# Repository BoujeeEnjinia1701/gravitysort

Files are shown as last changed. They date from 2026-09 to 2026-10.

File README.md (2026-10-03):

# GravitySort

     

**Area:** Mining · **TRL:** 3 of 9 (proof of concept on paper) · **Value-engineering target:** USD 455 (estimated cost USD 580) · **Difficulty:** 4 of 5

A mercury-free gravity concentrator for small-scale gold miners: a pedal- or motor-driven centrifugal bowl and shaking table combination that recovers fine gold without amalgamation.

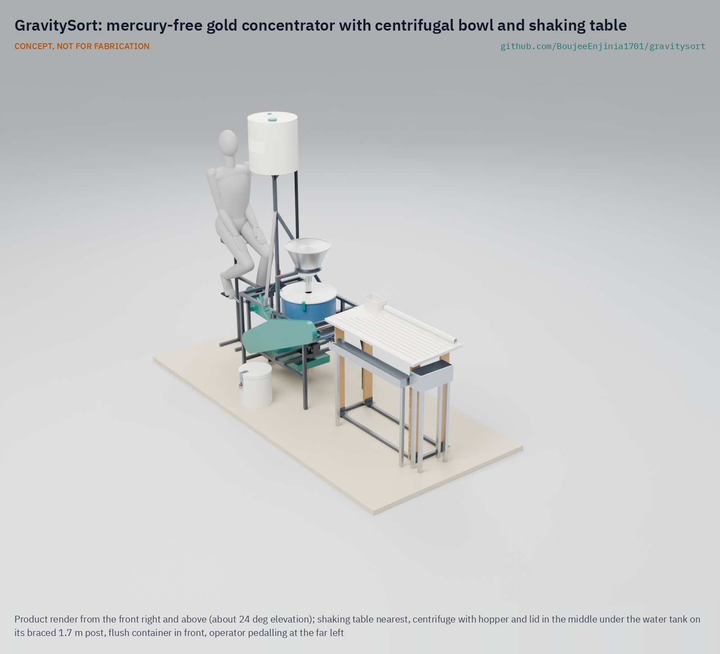
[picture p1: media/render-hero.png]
GravitySort: mercury-free gold concentrator with centrifugal bowl and shaking table, product render


[Exploded render](media/render-exploded.png) · [Detail render](media/render-detail.png) · [Interactive 3D model](media/viewer.html) · [Concept blueprint (PDF)](media/concept-blueprint.pdf) · [General arrangement GVS-DWG-001 (PDF)](cad/drawings/GVS-DWG-001.pdf) · [Sizing note GVS-CAL-001](docs/04-calcs/01-sizing.md) · [Prototype build plan](docs/05-build-plan.md) · [Design decisions register](docs/06-design-decisions.md) · [Review note](docs/REVIEW.md)

## Concept rationale

Miners use mercury because it catches fine gold cheaply, not because they want to. If a local workshop can build a machine that catches as much gold as mercury, or more, at a price a small group can pay back in weeks, miners gain an economic reason to stop, not only a legal one. GravitySort pairs the two gravity methods that each solve half the problem: a fluidized centrifugal bowl holds fine gold from a steady stream of milled ore, and a small shaking table cleans the bowl's concentrate down to a few tens of grams that can be smelted directly with borax. One pedal or motor drive runs both.

It is open and garage-buildable because commercial centrifuges and tables are imported, costly and hard to repair at a mine site. The frame is welded tube, the drive is bicycle parts and V-belts, the tub and tank are HDPE drums, and the bowl liner is cast in a printed mold, so a welder in a mining town can build, repair and adapt it, and anyone can check how it works.

## Burning platform

Artisanal and small-scale gold mining is the largest human source of mercury emissions to air: about 838 t in 2015, 37.7 % of the global total ([US EPA summary of the UNEP Global Mercury Assessment 2018](https://www.epa.gov/international-cooperation/mercury-emissions-global-context)). UNEP estimates that 10 to 15 million people work in the sector, including 4 to 5 million women and children, and that it produces about 12 to 15 % of the world's gold ([UNEP Global Mercury Partnership](https://www.unep.org/globalmercurypartnership/what-we-do/artisanal-and-small-scale-gold-mining-asgm)).

The pressure is rising. Gold averaged a record US$3,431/oz in 2025, up 44 % on the year ([World Gold Council](https://www.gold.org/goldhub/research/gold-demand-trends/gold-demand-trends-full-year-2025)), which raises the incentive to mine and the value of every gram lost. Yet whole-ore amalgamation in Colombian processing centers typically recovers only about 30 % of the gold ([Veiga et al., 2018](https://doi.org/10.1016/j.jclepro.2018.09.039)), so better gravity equipment can pay for itself as well as remove mercury.

## Where it could be used

### By industry

| Industry | Use |
| --- | --- |
| Artisanal and small-scale gold mining | Mercury-free primary concentration and clean-up for groups processing about 1 to 2 t of ore per day |
| Ore processing centers (entables) | Replace whole-ore amalgamation with a concentrate step, as national action plans require |
| Responsible gold supply chains | Refiners, traders and jewelers sourcing traceable mercury-free gold from certified small mines |
| Development and extension programmes | Demonstration unit for NGOs, cooperatives and government extension officers |
| Mining education | Teaching gravity separation in technical colleges and mining schools |
| Mineral exploration | Concentrating heavy minerals from stream sediment and trench samples in the field |

### By country or region

| Country or region | Why it matters there |
| --- | --- |
| Ghana | Illegal small-scale mining (galamsey) has silted rivers; Ghana Water reported raw water turbidity of about 14,000 NTU at one plant designed for 2,000 NTU ([GBC Ghana](https://www.gbcghanaonline.com/general-news/gwcl-attributes-water-supply-challenges-to-galamsey-activities/2024/)) |
| Peru | Gold mining cleared 95,751 ha of forest in the southeastern Peruvian Amazon from 1985 to 2017 ([Caballero Espejo et al., *Remote Sensing*, 2018](https://www.mdpi.com/2072-4292/10/12/1903)); Madre de Dios miners rely on mercury |
| Colombia | Mercury use in mining has been banned since July 2018 under Law 1658 of 2013 ([Mongabay](https://news.mongabay.com/2018/08/colombia-bans-the-use-of-mercury-in-mining/)), so miners need working alternatives |
| Philippines | In Benguet, the regional miners' federation reports all 15,000 members smelt gravity concentrates with borax instead of mercury ([Pure Earth](https://www.pureearth.org/filipino-gold-miners-borax-revolution/)), a model GravitySort's clean concentrate is designed to feed |
| European Union | Mercury exports and amalgamation in small-scale gold mining are prohibited ([Regulation (EU) 2017/852](https://eur-lex.europa.eu/eli/reg/2017/852/oj/eng)); EU buyers and programmes need mercury-free equipment to support abroad |

## What sparked the idea

The starting point was a single phrase in the Minamata Convention on Mercury, the treaty signed in Minamata, Japan, in October 2013. Its annex on artisanal and small-scale gold mining asks countries to eliminate the worst practices in the sector, including whole-ore amalgamation, in which mercury is mixed with all of the milled ore rather than with a small concentrate ([NRDC summary of the convention](https://www.nrdc.org/bio/susan-egan-keane/minamata-convention-what-it-means-artisanal-and-small-scale-gold-mining)). Ending that practice without ending the miners' income means putting a concentration step in front of the gold: something that turns tonnes of ore into a handful of heavy concentrate. GravitySort is that step, sized so the concentrate is small enough to smelt directly with borax and no mercury is needed at all.

## Problem

Artisanal and small-scale gold mining uses mercury to capture fine gold because it is cheap and works, poisoning miners, families and rivers. Mercury-free equipment exists but is costly and often recovers less fine gold. Design with, not for: requirements must come from co-design sessions and field trials with the intended users through a local partner.

Problem statement: [docs/01-problem.md](docs/01-problem.md)

## Concept

A welded steel frame carries a fluidized centrifugal bowl (220 mm lip, about 60 G at 730 rpm) that takes about 200 kg/h of ore milled below 2 mm, with a hopper screen above it and a water header tank on a braced 1.7 m post beside it, which gives the bowl's fluidization water its pressure without a pump. A pedal crank, or a 250 W motor through the lab's MotionCore module, turns the bowl through a jackshaft, bevel gearbox and V-belt; a bicycle disc brake stops it, and the lid opens only with the brake set. At the end of the day the same drive runs a 1,000 x 450 mm shaking table that cleans about 5.3 kg of bowl concentrate down to about 100 g for direct smelting with borax. The TRL 3 sizing note gives 48 W at the pedals, 1.19 m3/h of mostly recirculated water and about 1.55 t of ore per shift; about 60 % overall recovery on free-gold ore is assumed, compared with about 30 % for whole-ore amalgamation. The frame is 25 x 25 x 1.5 mm steel tube, and the machine weighs about 99 kg in six loads of 28 kg or less. The bowl is rinsed into a flush container and the table drops its gold into a box, both with padlock hasps. Value-engineering target: USD 455. Estimated cost of the constructable design: USD 580 (USD 125 over the target). All figures are estimates, not measurements.

Sizing note: [docs/04-calcs/01-sizing.md](docs/04-calcs/01-sizing.md) · Decisions: [GVS-DDR-001](docs/decisions/0001-trl2-review-decisions.md), [GVS-DDR-002](docs/decisions/0002-recommendations-accepted.md), [GVS-DDR-003](docs/decisions/0003-design-for-construction.md) · Drawing: [GVS-DWG-001](cad/drawings/GVS-DWG-001.pdf) · Model: [cad/src/model.py](cad/src/model.py)

Full design precis: [docs/02-concept.md](docs/02-concept.md) · Requirements: [docs/03-requirements.md](docs/03-requirements.md)

## Key components

- Welded steel base frame
- Feed hopper with 2 mm screen
- Centrifugal bowl with riffle rings and a cast polyurethane liner
- Fluidization water jacket and rotary union
- Spindle, bearings, splash tub and lid guard
- Bicycle disc brake with a parking latch and lid interlock, and a bicycle computer as the bowl speed display
- Drive: pedal crank, or a 250 W motor via MotionCore, through a jackshaft, bevel gearbox and V-belts, with guards
- Water header tank on a braced 1.7 m post, valve and flow meter
- Small shaking table on flexure legs, with an eccentric head on the frame end, a belt tensioner as its clutch, and a lockable concentrate box
- Flush container with a padlock hasp for the bowl concentrate

The working bill of materials is in [bom/bom.csv](bom/bom.csv).

## Building the prototype

The prototype build plan, [GVS-BLD-001](docs/05-build-plan.md), shows how to make every component and put the machine together, with a making sketch for each made part, close-ups of the joints and a picture for every assembly step. Making the design buildable changed some details of the concept (a member pair either side of each shaft, a hollow spindle that carries the fluidization water, a lid that lifts clear of the feed pipe, a table head bolted to the frame); every change is in [GVS-DDR-003](docs/decisions/0003-design-for-construction.md), open for review. Decisions still to be made are in the [design decisions register](docs/06-design-decisions.md). The plan is not yet built; building and testing to it is TRL 4 work.

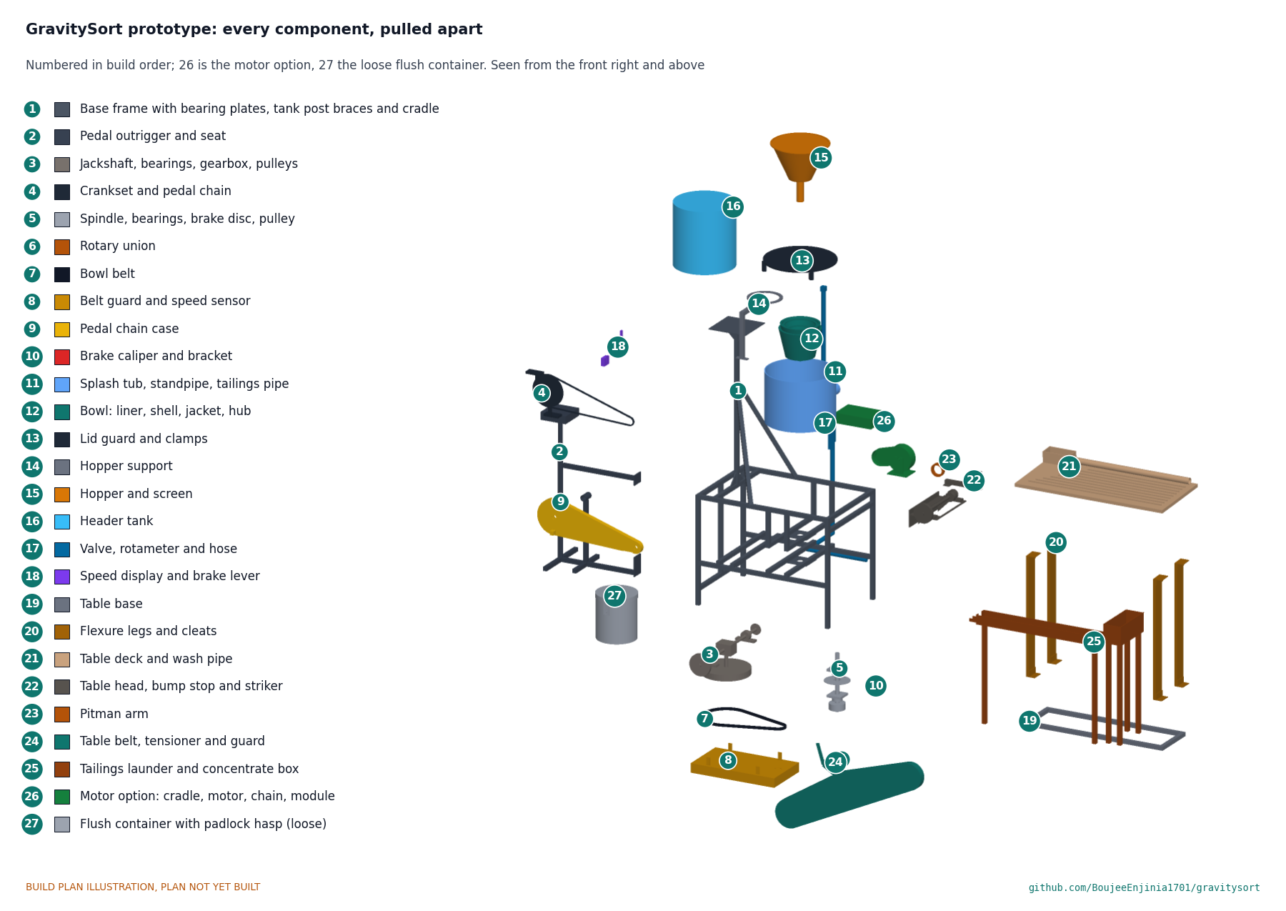
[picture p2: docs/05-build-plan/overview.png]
Every component of the GravitySort prototype, pulled apart and numbered in build order


## Safety

> Rotating machinery and water: the bowl spins at up to 850 rpm and coasts for about 20 s after the drive stops. Never run without the lid guard and belt and chain guards, keep hands, hair and loose clothing clear, and apply and park the brake before opening the lid. A rider can push the bowl past its 900 rpm limit; the bowl is designed with a large burst margin at that speed, but watch the speed display. Never use GravitySort with mercury or on untested mercury-contaminated tailings. Fence settling ponds. Concentrates can contain arsenic and lead minerals; wash hands after handling. Smelting, done outside this machine, reaches over 1,000 °C and needs a proper furnace and protective equipment. The motor option adds lithium cells; follow the MotionCore safety section. See [docs/02-concept.md](docs/02-concept.md#safety).

## Repository layout

| Folder | Contents |
| --- | --- |
| `docs/` | Problem, concept, requirements, calculations and design decisions |
| `cad/src/` | build123d Python source, the source of truth for all geometry |
| `cad/step/`, `cad/stl/` | Exported models for FreeCAD, other CAD tools and printing |
| `cad/drawings/` | 2D sketches and dimensioned drawings |
| `bom/` | Bill of materials |
| `electronics/` | KiCad schematics and PCB layouts |
| `firmware/` | Microcontroller code |
| `media/` | Renders, perspectives and photos |
| `build-log/` | Dated prototyping notes |

## Documentation

Controlled documents follow the portfolio [documentation standard](.kit/STANDARDS.md). Each carries a document ID (GVS-PRC-001 for the precis), a version and a revision history. Branded PDFs are built with `python .kit/render.py` and attached to GitHub Releases when a document is tagged, for example `GVS-PRC-001/v1.0`.

## Credits

Designed by Amish Chadha. See [CONTRIBUTORS.md](CONTRIBUTORS.md) for roles. To cite this design, use [CITATION.cff](CITATION.cff) (GitHub shows it as "Cite this repository").

AI assistance (Claude) was used to accelerate concept renders, prototype documentation and first-pass sizing calculations. Design direction and all decisions are Amish Chadha's, recorded in this repository's decision records (`docs/decisions/`).

## Licenses

- **Hardware** (CAD, drawings, BOM, electronics): [CERN-OHL-S v2](LICENSE)
- **Software** (firmware, scripts, notebooks): [MIT](LICENSE-SOFTWARE)

A project of the [Design Molecule](https://designmolecule.com) lab.

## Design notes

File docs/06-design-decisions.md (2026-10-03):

---
doc_id: GVS-DEC-001
title: GravitySort design decisions register
project: GravitySort
doc_type: Design decisions register
version: "0.7"
status: Draft
date: '2026-10-03'
author: Amish Chadha
license: CERN-OHL-S-2.0
revisions:
  - version: "0.1"
    date: '2026-10-01'
    author: Amish Chadha
    change: Register opened with the build plan; open decisions from the review notes, the decision records and the design for construction
  - version: "0.2"
    date: '2026-10-01'
    author: Amish Chadha
    change: Amish accepted the recommendations of open items 1 to 4, 9, 10 and 12 (GVS-DDR-003 accepted; R11 restated); moved to decisions made; open items renumbered 1 to 5
  - version: "0.3"
    date: '2026-10-01'
    author: Amish Chadha
    change: Table bump stop now in the model and build plan (follow-up note removed); buffer added to the items to confirm; Value engineering updated to USD 569
  - version: "0.4"
    date: '2026-10-01'
    author: Amish Chadha
    change: Amish accepted the change made while adding the bump stop (slotted pitman pin, leaning legs; GVS-DDR-003 Table 2); added to decisions made; no open item changed
  - version: "0.5"
    date: '2026-10-02'
    author: Amish Chadha
    change: "Amish approved the recommendations for open decisions 1 to 5; moved to decisions made"
  - version: "0.6"
    date: '2026-10-02'
    author: Amish Chadha
    change: "Decisions of 2026-10-02 carried into the model, BOM, calculations and build plan; one open decision added (tank on the centre line and the tipping criterion, made to carry out decision 1); Value engineering updated to USD 580"
  - version: "0.7"
    date: '2026-10-03'
    author: Amish Chadha
    change: "Open item 1 decided by Amish on 2026-10-03 (option a: tank post on the centre line, braced, 10 degree any-direction tip criterion); moved to decisions made"
---

# GravitySort design decisions register

Every design decision still to be made, and every decision made, in one place. Each decision is argued in full in its decision record under `docs/decisions/`; this register is the index Amish works from. The build plan (`docs/05-build-plan.md`, GVS-BLD-001) describes the design as it stands and does not list open decisions.

## Open decisions

None. Open item 1 (tank post position and tip criterion) was decided on 2026-10-03.

## To confirm when parts are bought

| # | What to confirm | Why it matters | Source |
| --- | --- | --- | --- |
| 1 | The two flanged bearing units (UCF205 class): 95 mm square flange, bolts 70 mm apart, 25 mm bore with set screws | They set the holes in the two bearing plates | GVS-DDR-003, P2 |
| 2 | The shaft flange hub: 25 mm bore, 80 mm flange, four holes on a 60 mm circle, room for a 6 mm cross pin | It joins the bowl and jacket to the spindle | GVS-DDR-003, P4 |
| 3 | The rotary union: 1/2 in BSP on the shaft side, side water port, seal drag near 0.10 N m | Pedal power (R6) assumes this drag; the nipple welded into the spindle must match its thread | GVS-CAL-001 sections 7 and 10 |
| 4 | The right-angle 1:1 gearbox: through input shaft about 33 mm above its feet, feet about 100 x 80 mm, output shaft long enough for the drive pulley 85 mm below the feet | It sets the jackshaft height and the member spacing | GVS-DDR-003, P9; GVS-PRC-001 open questions |
| 5 | The four 20 mm pillow blocks (UCP204 class, centre height 33.3 mm, bolts 95 mm apart) | Two set the jackshaft height on the gearbox members; two carry the table head shaft | GVS-DDR-003, P8 and P14 |
| 6 | The two rubber pipe grommets for 63 mm and 75 mm pipe that seal in a 6 mm curved wall | They seal the standpipe and tailings pipe without welding | GVS-DDR-003, P6 |
| 7 | The 430 mm HDPE drum: flat floor, 6 mm wall, food-grade or clean | It is the splash tub | GVS-DDR-003, P6 |
| 8 | The used bicycle parts: a bottom bracket shell that can be cut from a scrap frame and welded, crank axle length, a 27.2 mm seat post | They set the outrigger's pedal post and seat tube | GVS-DDR-003, P8 |
| 9 | The disc caliper's mount (post mount or the older standard) and the disc's 6-bolt pattern | They set the caliper bracket holes and the brake flange | GVS-DDR-003, P15 |
| 10 | MotionCore: the reference hub motor's no-load speed (assumed 250 rpm), a sprocket on its disc mount, axle length for dropouts 76 mm apart inside, a speed limit that maps to 900 rpm at the spindle, a brake input for the lid switch | They set the 1.2:1 step-up, the cradle and the motor speed cap | GVS-DDR-002, item 14; review note 2026-09-25 |
| 11 | The bump stop's rubber buffer: 40 mm across, 30 mm long, about 55 Shore A, M8 female thread, rated 800 N or more in compression | The stop's force, squeeze and setting range are sized for this buffer (GVS-CAL-001 section 9) | GVS-DDR-003, A2 |

## Value engineering

Value-engineering target: USD 455 (a hypothetical control target, not a limit; Amish, 2026-10-01). Estimated cost of the constructable design: USD 580 (USD 125 over the target), excluding the MotionCore kit, reference motor and battery. Main cost drivers and savings worth trying:

- **Main cost drivers.** The jackshaft, gearbox, chains and pulleys ($60); the jacket, hub and rotary union ($55); the table stand and head ($52); the frame ($47); the bowl ($46); the water supply ($41). Making the design buildable added $103, mostly the table head and tensioner, more frame tube and plate, and the tub fittings (GVS-DDR-003); the table bump stop adds $11 more (bracket and striker $6, buffer and fixings $5); the decisions of 2026-10-02 add $11 (the braced 1.7 m tank post $4, the flush container with its hasp $7).
- **A quarter-turn belt instead of the bevel gearbox,** about $25 less (GVS-DDR-001, item 1). Worth a test, since a used gearbox is also the hardest part to find.
- **Used bearing units and pillow blocks** from scrap farm or factory machinery, about $10 to $15 less across the six bearings.
- **Run the table head shaft in two plain bronze bushes** in the head plate instead of two pillow blocks, about $8 less; the shaft turns slowly (about 300 rpm).
- **Take the table wash water from the main hose** with a tee at the rotameter instead of a separate branch and valve, about $4 less.
- **Buy steel as offcuts** and use one plate thickness (5 mm) throughout, a few dollars and a little mass.
- Not recommended: the non-fluidized bowl (about $45 less) or building the table later (about $100 deferred), because both change what the machine does.

## Decisions made

| Date | Decision | Decided by | Record |
| --- | --- | --- | --- |
| 2026-09-25 | TRL 2 review items: two stages, fluidized bowl with rotary union, cast PU liner, pedal baseline with the MotionCore option and one time-shared drive, battery left to the user, borax smelting outside the machine, partner screening criterion | Amish: "i accept all your recommendations, go with them across all repos." | GVS-DDR-001, GVS-DDR-002 |
| 2026-09-25 | Budget from $350 to $450; R12 restated for the pedal drive; frame in 25 x 25 x 1.5 mm tube; 3/4 in fluidization hose and graded holes; disc brake with parking latch and lid interlock pin, speed display, 1.2:1 motor step-up, MotionCore lid switch | Amish, same instruction | GVS-DDR-002, items 1, 9, 10, 11a and 14 |
| 2026-09-26 | Budget set to $455 to cover the priced BOM | Amish: "i approve all the budget items." | GVS-DDR-002 v0.2 |
| 2026-09-26 | GravitySort chosen for the first batch of product renders | Amish | `docs/REVIEW.md`, session of 2026-09-26 |
| 2026-09-30 | Make the design physically buildable while drawing the build plan; the changes are recorded in GVS-DDR-003 and were accepted on 2026-10-01 (below) | Amish: "If you are realising that the design cannot be built as per concept - fix the design assumptions to match and be physically feasible as you draw the illustrations." | GVS-DDR-003 |
| 2026-09-30 | Open decisions are kept out of the build plan, in this register | Amish: "don't log outstanding decisions in this build plan - that is not the place for it. that should be in a separate design document logged and named as such" | `.kit/STANDARDS.md` section 18 |
| 2026-10-01 | The budget is a value-engineering target, not a limit; cost is reported against it | Amish: "the budgets are a hypothethical control target to ensure we are thinking along a value engineering lens. its ok to ensure wording reflects that the hypothesis budget was x - the real cost being accrued is y" | `.kit/STANDARDS.md` section 18 |
| 2026-10-01 | Design for construction accepted: the changes P1 to P15 and their knock-on changes, as made | Amish: "i agree with your recommendations for both GrowRider and GravitySort" | GVS-DDR-003, Tables 1 and 2 |
| 2026-10-01 | R11 restated: total 100 kg or less, every load 30 kg or less (was 80 kg in all); the 95.7 kg design meets it on paper. Follow-up: try the savings of about 16 kg (option b) at TRL 4 | Amish: "i agree with your recommendations for both GrowRider and GravitySort" | GVS-DDR-003, A1; GVS-REQ-001 v0.7 |
| 2026-10-01 | Asymmetric table stroke: an adjustable rubber bump stop at the return end of the stroke for the prototype. Follow-up: a toggle head (option b) only if the first test shows the stop is not enough | Amish: "i agree with your recommendations for both GrowRider and GravitySort" | GVS-DDR-003, A2 |
| 2026-10-01 | Pedal position: keep the bicycle-style seat, about 910 to 960 mm up, seat post adjustable. Follow-up: check with two riders at TRL 4 | Amish: "i agree with your recommendations for both GrowRider and GravitySort" | GVS-DDR-003, A3 |
| 2026-10-01 | Containment of a liner fragment: check by calculation before any spin test; add a steel band round the tub at the bowl lip height only if the check fails | Amish: "i agree with your recommendations for both GrowRider and GravitySort" | GVS-CAL-001 section 10; review note 2026-09-25 |
| 2026-10-01 | Lid: keep the plain 10 mm HDPE lid, no sight window | Amish: "i agree with your recommendations for both GrowRider and GravitySort" | Review note 2026-09-26, item 4 |
| 2026-10-01 | Renders: the cranks turned 100 degrees from top dead centre is a render pose only; the model keeps its crank angle | Amish: "i agree with your recommendations for both GrowRider and GravitySort" | Review note 2026-09-26, item 1 |
| 2026-10-01 | Table bump stop, change made to let the deck strike the stop: the pitman pin works in a 12 x 20 mm slot in the deck cheeks (8 mm of free play), and the plywood legs are set leaning about 5 mm so they press the deck on the buffer with about 200 N. Accepted as made; no design change | Amish: "I approve of your recommendations for PicoFlow and GravitySort" | GVS-DDR-003, Table 2 (v0.4) |
| 2026-10-02 | Head for the fluidization supply: raise the header tank post to 1.7 m (option a), braced so a full 60 L tank cannot tip it; no pump on the fluidization line. Carried into the model, drawings, build plan, BOM and GVS-CAL-001 v0.8 on 2026-10-02 (8.6 kPa at the union at mid-tank) | Amish: "i approve your recommendations for all 555 open decisions." | GVS-DDR-001, item 11b |
| 2026-10-02 | Water at pedal-only sites: gravity supply from upstream is the site rule for the first field trial; where that is impossible, a bought treadle or hand pump worked in turns by the crew, or a small 12 V pump at sites with the MotionCore battery | Amish: "i approve your recommendations for all 555 open decisions." | GVS-DDR-001, item 12 |
| 2026-10-02 | R2 restated as 200 kg/h of feed time, about 1.55 t in an eight-hour shift with three flush stops; the design feed stays at 200 kg/h | Amish: "i approve your recommendations for all 555 open decisions." | GVS-DDR-001, item 13 |
| 2026-10-02 | First co-design partner and country: Colombia, where the mercury ban is in force, with a miners' cooperative introduced through the Alliance for Responsible Mining in Medellin as the first candidate to approach | Amish: "i approve your recommendations for all 555 open decisions." | GVS-DDR-001, item 8b |
| 2026-10-02 | Concentrate security: padlock hasps on both the concentrate box and the flush container as the baseline, and a two-person rule for opening them proposed to the partner; both to be confirmed with the partner. Flush container with hasp added to the model and BOM (item 23) on 2026-10-02 | Amish: "i approve your recommendations for all 555 open decisions." | GVS-PRC-001, open questions |
| 2026-10-03 | Open item 1, option (a): the 1.7 m tank post stands on the centre line and is braced; "a full tank cannot tip it" means a 10 degree slope in any direction with a full tank (tips at 13.5 degrees, 193 N side push at the tank, better than the earlier 1.25 m layout at 11.6 degrees); no wider feet or outriggers | Amish: "GravitySort - i accept your recommendation" | GVS-CAL-001 v0.8 section 11; [REVIEW.md](REVIEW.md), session 2026-10-03 |

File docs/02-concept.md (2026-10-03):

---
doc_id: GVS-PRC-001
title: GravitySort design precis
project: GravitySort
doc_type: Design precis
version: "1.0"
status: Draft
date: '2026-10-02'
author: Amish Chadha
license: CERN-OHL-S-2.0
revisions:
- version: "0.1"
  date: '2026-09-25'
  author: Amish Chadha
  change: Initial scaffold
- version: "0.2"
  date: '2026-09-25'
  author: Amish Chadha
  change: Populate to TRL 2 (architecture, components, first-order numbers, gold balance, safety, media)
- version: "0.3"
  date: '2026-09-25'
  author: Amish Chadha
  change: TRL 3 update. Design choices adopted as recommended under Amish's 2026-09-25 instruction (GVS-DDR-001), open for his review; numbers from GVS-CAL-001; bowl brake, lid interlock and speed display added; MotionCore cost $335
- version: "0.4"
  date: '2026-09-25'
  author: Amish Chadha
  change: Recommendations accepted by Amish (DDR-002). Frame, pedal outrigger and table stand in 25 x 25 x 1.5 mm tube (77.3 kg); budget $450, parts $455; R12 restated for the pedal drive
- version: "0.5"
  date: '2026-09-26'
  author: Amish Chadha
  change: Budget approved by Amish ($455)
- version: "0.6"
  date: '2026-10-01'
  author: Amish Chadha
  change: Constructable design (GVS-DDR-003); components, mass (95.7 kg) and cost ($558 against the $455 value-engineering target) updated; build plan GVS-BLD-001 and design decisions register GVS-DEC-001 added
- version: "0.7"
  date: '2026-10-01'
  author: Amish Chadha
  change: GVS-DDR-003 accepted by Amish; R11 restated (100 kg total, loads 30 kg or less) and met on paper; table stroke made asymmetric by an adjustable rubber bump stop
- version: "0.8"
  date: '2026-10-01'
  author: Amish Chadha
  change: Table bump stop now in the model and build plan (component 15; BOM items 21 and 22); mass 96.5 kg; cost $569 (USD 114 over the target)
- version: "0.9"
  date: '2026-10-02'
  author: Amish Chadha
  change: "Header post, site water, R2, concentrate security and first partner as decided on 2026-10-02 (GVS-DEC-001)"
- version: "1.0"
  date: '2026-10-02'
  author: Amish Chadha
  change: "Decisions of 2026-10-02 carried into the design: tank on a 1.7 m braced post on the centre line, flush container with a padlock hasp (item 23); figures from GVS-CAL-001 v0.8 (99.3 kg, $580, 2.10 m tall)"
---

# GravitySort design precis

## Summary

GravitySort is a two-stage, mercury-free gravity concentrator for small mining groups. A fluidized centrifugal bowl (220 mm across the lip, about 60 G at 730 rpm) catches fine gold from about 200 kg/h of milled ore, and a small shaking table (1,000 x 450 mm) cleans the day's bowl concentrate (about 5.3 kg) down to about 100 g, small enough to smelt directly with borax. One drive, either a pedal crank or a 250 W motor through the lab's MotionCore module, runs the bowl by day and the table at clean-up. A bicycle disc brake stops the bowl, and the lid can be opened only with the brake set. The whole machine is a welded frame of 25 x 25 x 1.5 mm steel tube about 2.8 m long, about 99 kg in six loads of 28 kg or less, built from bicycle parts, bearings, V-belts, HDPE drums and a cast polyurethane bowl liner. The sizing note GVS-CAL-001 gives 48 W at the pedals at 60 G and 1.19 m3/h of water; about 60 % overall gold recovery on free-gold ore is assumed, compared with about 30 % typical of whole-ore amalgamation in Colombian processing centers ([Veiga et al., 2018](https://doi.org/10.1016/j.jclepro.2018.09.039)). Value-engineering target: USD 455. Estimated cost of the constructable design: USD 580 (USD 125 over the target). Making every part buildable (GVS-DDR-003, accepted by Amish on 2026-10-01) took the mass over R11's original 80 kg total; Amish restated R11 to 100 kg or less in all, with every load 30 kg or less, so it is met on paper. R5 and R6 are at risk; R2 is met on paper since Amish restated it on 2026-10-02. The prototype build plan is GVS-BLD-001 (`docs/05-build-plan.md`); open decisions are in GVS-DEC-001 (`docs/06-design-decisions.md`). All figures are estimates for review, not measurements.

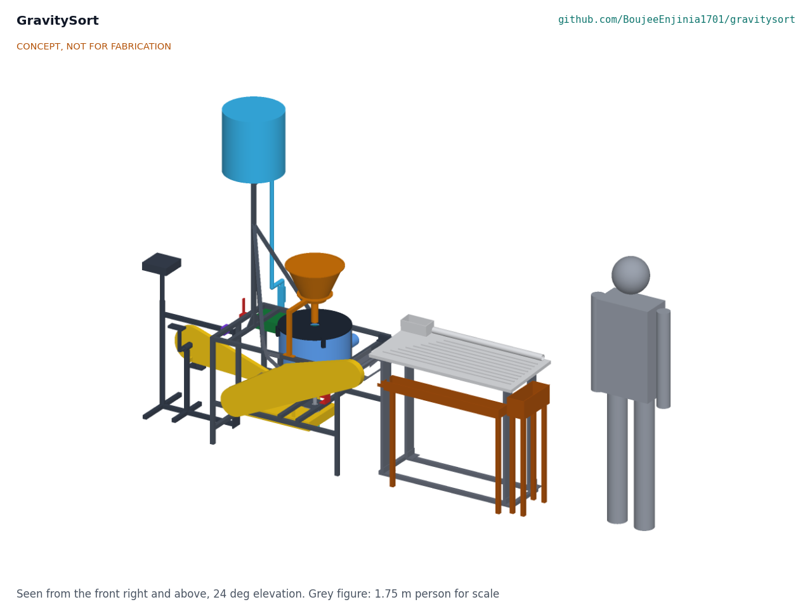
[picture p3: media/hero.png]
Hero render


*Figure 1. GravitySort with a 1.75 m person for scale. Pedal station on the left, centrifuge frame with hopper and water tank in the middle, shaking table on the right. Generated from the TRL 3 model `cad/src/model.py`; general arrangement in drawing GVS-DWG-001.*

## Design approach

### How it works

1. **Feed.** Ore milled to below about 2 mm is shovelled or washed onto the 2 mm punched screen on top of the hopper. Oversize goes back to the mill. Water from the header tank carries the undersize down a feed pipe into the centre of the bowl as a slurry of about 30 % solids.
2. **Concentrate in the bowl.** The bowl spins at 600 to 850 rpm (40 to 80 G at 100 mm radius; 46 to 63 G across the four rings at 730 rpm). Slurry climbs the conical wall and passes over four riffle rings. Dense particles (gold, about 19 g/cm3, and heavy minerals) settle in the rings; light gangue (quartz, about 2.7 g/cm3) spills over the lip into the splash tub and out through the tailings launder to a settling pond. Water injected through about 89 holes of 1.0 mm in the rings from a rotating jacket keeps the bed loose (fluidized), so heavy particles can keep replacing light ones instead of the rings packing hard.
3. **Flush.** About every 2 h the operator stops feed, stops the drive, applies and parks the brake, opens the lid and rinses the rings into a lockable container: about 1.3 kg of heavy concentrate per flush (GVS-CAL-001).
4. **Clean on the table.** At the end of the day the belt tension is moved from the bowl drive to the table drive, and the day's bowl concentrate (about 5.3 kg) is fed onto the shaking table, likely in two passes to reach about 100 g. The table's asymmetric stroke and cross-flow of water spread particles by density: gold walks to the end of the riffles and drops into a lockable concentrate tray; lighter material washes off the front edge and is re-run.
5. **Smelt, outside this machine.** The final concentrate (about 100 g or less) is dried and smelted with borax in a small furnace, as in the Benguet method ([Appel and Na-Oy, 2012](https://www.journalhealthpollution.org/doi/full/10.5696/2156-9614-2.3.5)). No mercury is used at any step.

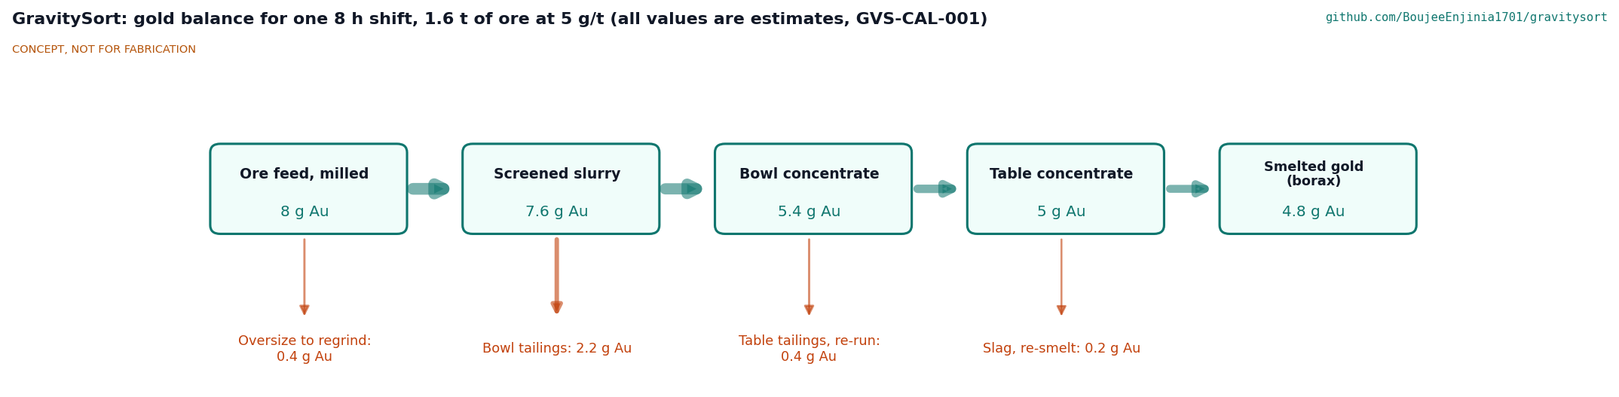
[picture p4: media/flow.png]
Gold balance


*Figure 2. Gold balance for one 8 h shift at 200 kg/h on a reference ore of 5 g/t (GVS-CAL-001 section 13). All values are assumed stage recoveries, not results: oversize loss 5 %, bowl recovery of screened gold about 71 %, table recovery about 93 %, smelting recovery about 96 %. Overall about 60 %.*

### Drive

The pedal crank (48-tooth chainring) drives a jackshaft through a 12-tooth freewheel (4:1). A right-angle bevel gearbox turns the drive to a vertical shaft carrying a 300 mm pulley, which belts to a 100 mm pulley on the bowl spindle (3:1). At a cadence of 61 rpm the bowl turns at about 730 rpm and the rider supplies about 48 W (GVS-CAL-001). The freewheel lets the bowl coast when the rider stops, and lets a MotionCore motor drive the jackshaft through its own chain without turning the pedals. For the table, a 140 mm take-off pulley on the jackshaft drives a 125 mm pulley on the table's eccentric head through a V-belt that is slack (disengaged) unless its tensioner is set; a cadence of 54 to 67 rpm gives 240 to 300 strokes/min.

The optional motor is the MotionCore kit (module, hardwired emergency stop, brake inputs and an independent speed limit) with its reference 250 W geared hub motor, on any 20 to 58 V pack that MotionCore accepts. The pack is left to the user (GVS-DDR-001 item 6). The hub motor carries a sprocket on its disc mount and chains to the jackshaft with a step-up of about 1.2:1, chosen so that the motor's no-load speed at full pack voltage gives at most 900 rpm at the bowl. MotionCore's speed sensor reads the spindle, and its speed limit is set to 900 rpm.

**Brake, interlock and speed display.** Because the freewheel lets the bowl coast for about 20 s, a 160 mm bicycle disc rotor on the spindle and a mechanical caliper (BOM item 18) stop it; the lever has a parking latch, and a pin on the same cable locks one lid clamp, so the lid opens only with the brake set. With the motor, a lid switch on a MotionCore brake input also removes torque. A wired bicycle computer (item 19) with its magnet on the spindle pulley, set to a 1,667 mm wheel size, reads the bowl speed divided by 10. Gearing does not cap the pedal speed, since 900 rpm needs only a 75 rpm cadence. R12 as restated (GVS-DDR-002, item 9) therefore relies, for the pedal drive, on a burst safety factor of at least 10 at the highest reachable speed (17 at 1,200 rpm in GVS-CAL-001) and on the speed display.

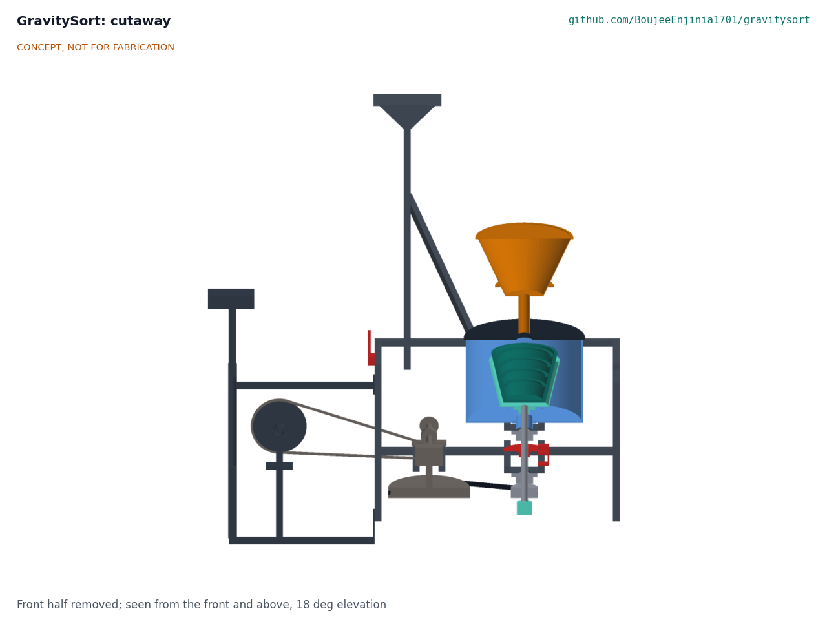
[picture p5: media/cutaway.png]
Cutaway


*Figure 3. Section through the centrifuge axis, looking from the front. Bowl (3) with riffle rings inside the fluidization jacket (4), spindle, bearings and brake disc (5, 18) below, splash tub (6) around, hopper (2) and feed pipe above.*

## Main components

Table 1. Main components. Numbers match `bom/bom.csv` and Figure 4.

| # | Component | Choice at TRL 3 | Notes |
| --- | --- | --- | --- |
| 1 | Base frame | 25 x 25 x 1.5 mm mild steel square tube, welded, 900 x 600 x 700 mm: lower rails carrying the gearbox and spindle member pairs, tub members on drop posts, bearing plates, a 1.7 m tank post with two braces and a cradle (GVS-DDR-003; GVS-DEC-001) | Painted; the pedal outrigger and table head bolt to its ends. 16.4 m of tube; spindle member safety factor 3.9 (GVS-CAL-001) |
| 2 | Feed hopper | Sheet steel cone in a support ring on a post from the front top rail, 2 mm punched stainless screen on top, 44 mm feed pipe ending 15 mm above the lid over the bowl centre | Screen removable for cleaning; the lid lifts off past the pipe |
| 3 | Centrifugal bowl | 220 mm lip, 130 mm base, 180 mm deep; four riffle rings 6 mm thick and 12 mm deep at a 38 mm pitch; about 89 fluidization holes of 1.0 mm, graded toward the lower rings; 8 mm cast polyurethane liner (Shore 80 to 90A) in a 3D-printed mold on a 4 mm GFRP shell | No lathe needed; liner replaceable. Decided by Amish, 2026-09-25: go with recommendation (GVS-DDR-001 item 4, GVS-DDR-002) |
| 4 | Fluidization jacket and rotary union | Sealed 4 mm GFRP jacket with a 12 mm gap and a bonded closing ring, rotating with the bowl on a pinned flange hub, fed up the hollow spindle from a 1/2 in rotary union at its foot by a 3/4 in hose, 8 to 15 L/min | Decided by Amish, 2026-09-25: go with recommendation (GVS-DDR-001 items 3 and 11, GVS-DDR-002); a 1/2 in hose starves the jacket (GVS-CAL-001 section 6) |
| 5 | Spindle and bearings | 25 x 2 mm stainless tube, two UCF205 flanged insert bearing units hung under welded plates, 100 mm driven pulley on a taper bush | Upper bearing shielded by a standpipe through the tub floor; first critical speed about 2,710 rpm |
| 6 | Splash tub and launder | Cut HDPE drum, 430 mm diameter, bolted on the tub members; 75 mm tailings pipe through a rubber grommet to the settling pond | |
| 7 | Bowl lid guard | 10 mm HDPE disc, two toolless over-centre clamps to the tub, 60 mm feed hole | One clamp is locked by the brake interlock pin |
| 8 | Pedal station | Used bicycle bottom bracket, crank, 48T chainring, pedals and seat on a welded outrigger bolted to the frame end | Adjustable seat |
| 9 | Jackshaft and gearbox | 20 mm shaft on two bearings, 12T freewheel, 1:1 right-angle bevel gearbox, 300 mm drive pulley, motor sprocket, 140 mm table take-off pulley | Bevel box from a used agricultural or garden machine is an option; a quarter-turn belt is a cost-down option awaiting Amish |
| 10 | Drive belts | A-section V-belts: bowl (horizontal) and table (inclined, clutch by tensioner) | |
| 11 | Guards | Perforated sheet covers over belts, pulleys and chain | Must be fitted before running |
| 12 | MotionCore kit and reference motor | MotionCore module, e-stop, brake inputs and speed sensor, with the 250 W geared hub motor | Shared component; $335 ($265 kit plus $70 motor, MTC-CAL-001), not in the GravitySort cost |
| 13 | Water header tank | 60 L HDPE drum on a cradle 1.7 m above ground, on a post on the machine's centre line braced to both top side rails; ball valve, 2 to 20 L/min rotameter, 3/4 in hose | Decided by Amish, 2026-10-02 (GVS-DEC-001): 8.6 kPa at the union at mid-tank against 8.1 kPa needed; with a full tank the machine stands on a 13.5 degree slope (GVS-CAL-001 sections 6 and 11). Filled by gravity from upstream, or by a treadle, hand or 12 V pump where that is impossible |
| 14 | Shaking table deck | 1,000 x 450 mm, 18 mm marine plywood faced with HDPE, tapered riffles, feed box, 2 to 4 degrees cross tilt | Adjustable tilt |
| 15 | Table stand and head motion | Plywood flexure legs on a welded base; head plate and shelf bolted to the frame's table end, eccentric head shaft with a 125 mm pulley and pitman arm, 15 mm stroke at 240 to 300 strokes/min; belt tensioner as the table clutch | The stroke is made asymmetric by an adjustable rubber bump stop at the return end, decided by Amish on 2026-10-01 (GVS-DDR-003, A2), with a toggle head only if the first test shows the stop is not enough. The deck strikes a 40 x 30 mm rubber buffer on a bracket on the frame's table end at the end of each forward stroke; the pitman pin works in a slot and the plywood legs push the deck onto the buffer. Set 3 mm in, the stop gives 2.1 G against 0.6 G at the head end (GVS-CAL-001 section 9; items 21 and 22). About 15 W at the pedals |
| 16 | Concentrate tray | Tailings launder under the table's front edge, lockable concentrate box with a padlock hasp under its far (gold) end | Security for the operator |
| 18 | Bowl brake and lid interlock | 160 mm bicycle disc rotor on a flange and collar on the spindle, mechanical caliper, lever with parking latch; lid interlock pin on the same cable | New at TRL 3 (R12) |
| 19 | Bowl speed display | Wired bicycle computer, magnet on the spindle pulley, wheel size 1,667 mm so it reads rpm divided by 10 | New at TRL 3 (R3) |
| 20 | Motor cradle | 6 mm cradle with two dropouts bolted on the back lower rail; motor chain guard | Motor option only (GVS-DDR-003) |
| 21, 22 | Table bump stop | Tube bracket bolted on the frame's table-end top rail; bought rubber buffer on an M8 stud with lock nuts; steel striker angle under the deck | Gap set 2 to 6 mm by the lock nuts (GVS-DDR-003, A2) |
| 23 | Flush container | Bought 10 L HDPE pail with a lid; a padlock hasp riveted on, staple on the pail and strap on the lid | The bowl is rinsed into it at each flush; decided by Amish, 2026-10-02 (GVS-DEC-001); a two-person rule is proposed to the partner |

Item 17 (hardware, hoses and sealant) is in the BOM and only partly modelled.

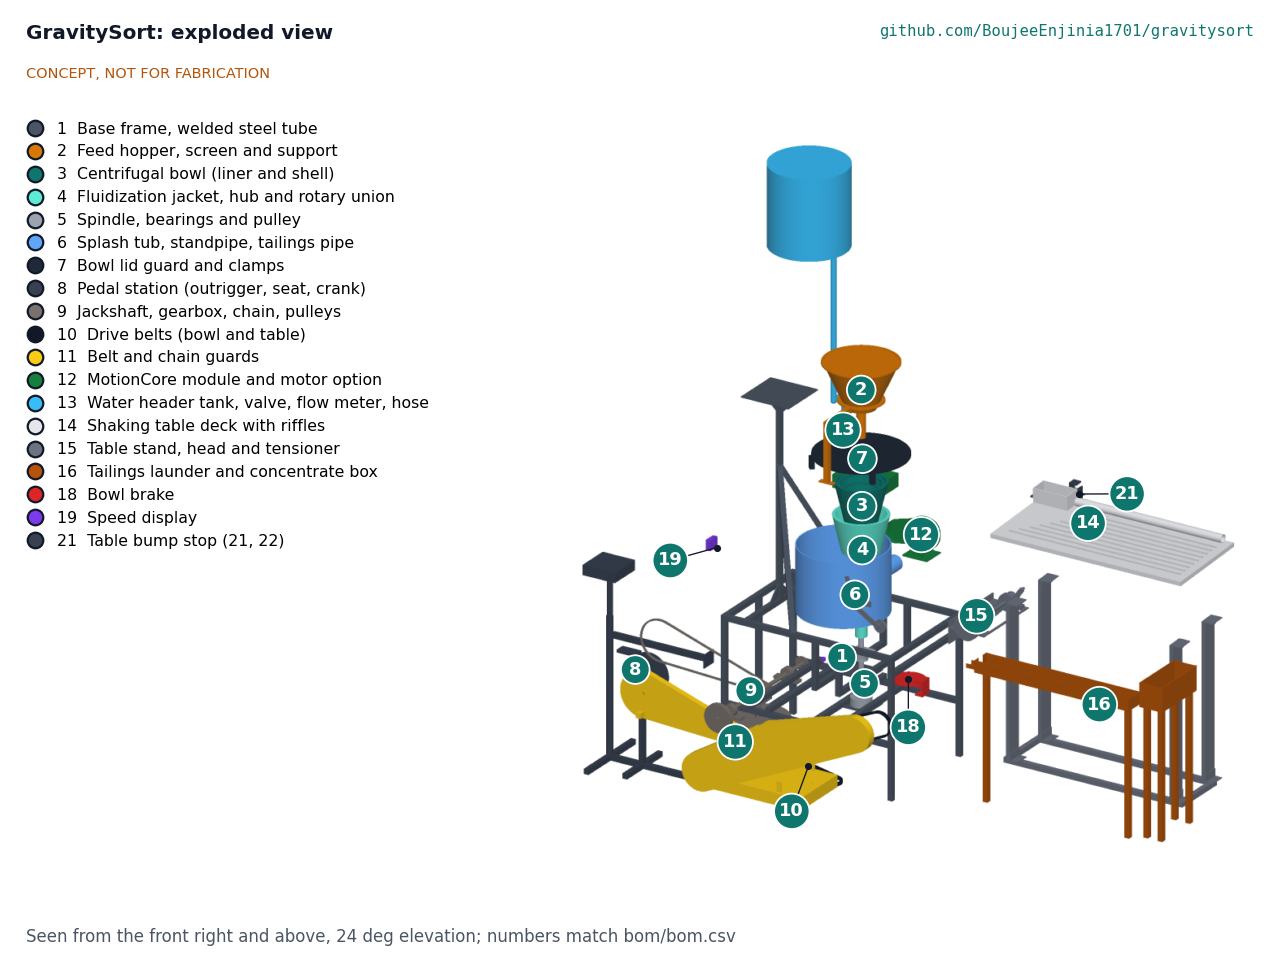
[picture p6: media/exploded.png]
Exploded view


*Figure 4. Exploded view with numbered callouts matching Table 1 and the BOM.*

## Sizing summary

The TRL 2 first-order numbers have been checked by calculation in GVS-CAL-001 (`docs/04-calcs/01-sizing.md`, printed by `docs/04-calcs/sizing.py`). Table 2 gives the main results; every value is an estimate.

Table 2. Main numbers from GVS-CAL-001.

| Quantity | Value | Note |
| --- | --- | --- |
| Bowl speed for 60 G at 100 mm radius | 733 rpm (730 rpm nominal) | 598 rpm for 40 G, 846 rpm for 80 G |
| Drive ratio, pedal to bowl | 12:1 (4:1 chain, 1:1 bevel, 3:1 belt) | 61 rpm cadence gives 730 rpm |
| Feed rate | 200 kg/h solids; 1.55 t per 8 h shift | Three 5 min flush stops; R2 is 200 kg/h of feed time (restated 2026-10-02) |
| Water | 0.467 m3/h slurry plus 0.72 m3/h fluidization: 1.19 m3/h | 60 L header lasts 3 min; gravity supply from upstream to a tank top 2.1 m up, or a pump (about 6.8 W hydraulic) where that is impossible |
| Fluidization supply | 8.6 kPa at the union at mid-tank (7.1 to 10.1 kPa) with a 3/4 in hose from the tank on its 1.7 m post; net 10.4 to 20.6 kPa across the ring holes | 8.1 kPa at the union gives 10 kPa at every ring at 600 rpm; a 1/2 in hose would leave 1.4 kPa |
| Input power at the pedals | 48.2 W at 60 G; 62.8 W at 80 G | Drivetrain 0.839; union seal drag assumed |
| Motor option | 5.2 times power margin at 60 G; 0.55 kWh per shift | 70 % motor and controller efficiency at light load |
| Bowl concentrate per flush | 1.33 kg; mass pull 0.33 % | Groove volume 0.89 L at 60 % fill |
| Table reduction | 53:1 needed for 100 g from 5.3 kg | Two passes at about 8:1 give about 83 g |
| Rotating group | 6.47 kg, 0.0566 kg m2 with the drive; 165 J at 730 rpm | 447 J at 1,200 rpm |
| Burst safety factor at 1,200 rpm | 16 (jacket wall), 30 (bowl shell), 51 (ring lips) | Assumes sound lamination and a bonded liner |
| Stop time from 850 rpm | 0.6 s with the brake; about 20 s coasting | R12 asks for 15 s or less |
| Size and mass | 2.78 x 0.79 x 2.10 m; 99.3 kg in six loads, heaviest 27.3 kg | R11 met on paper: 100 kg or less in all, every load 30 kg or less (restated from 80 kg by Amish, 2026-10-01; 77.3 kg for the concept; GVS-DDR-003) |
| Parts cost | $580 | `bom/bom.csv`; MotionCore ($335) and battery excluded; USD 125 over the $455 value-engineering target |
| Header tank post | Tips sideways on a 13.5 degree slope with a full tank; post above the braces safety factor 2.3 at the push that tips it | Tank on the centre line; 190 N pushed at the tank tips the machine on level ground |

The daily motor energy of 0.55 kWh is a little more than the energy of a SwapCell reference pack (about 468 Wh nominal); a larger pack or a 150 to 200 W solar panel would cover a shift. The pack stays the user's choice.

## Key design choices

Each of these was recommended at TRL 2. Status: Decided by Amish, 2026-09-25: go with recommendation (GVS-DDR-001, GVS-DDR-002).

1. **Two stages, centrifuge then table,** rather than a centrifuge alone (whose concentrate is too large to smelt) or a table alone (which loses fine gold at this throughput and needs more water).
2. **Fluidized bowl** with a rotary union, rather than a simpler non-fluidized bowl that packs hard and needs flushing every 15 to 30 min. The non-fluidized bowl stays documented as a low-cost variant.
3. **Cast polyurethane liner** in a printed mold on a GFRP shell, rather than a turned HDPE bowl (needs a lathe) or a printed bowl (wears quickly on quartz).
4. **One drive, time-shared** between bowl and table, rather than two drives. Saves a motor or a second pedal station.
5. **Pedal drive as the baseline,** MotionCore motor as an option, with the battery left to the user.
6. **Direct smelting with borax** as the recommended final step, outside this machine.

Items new at TRL 3 are also decided by Amish, 2026-09-25: go with recommendation (GVS-DDR-002): the brake with parking latch and lid interlock pin, the bicycle computer speed display, the 1.2:1 motor step-up, the MotionCore lid switch on a brake input, the 3/4 in fluidization hose and graded holes (items 11a and 14), R12 restated for the pedal drive (item 9) and the lighter frame tube (item 10). Amish decided the remaining items on 2026-10-02 (GVS-DEC-001): a 1.7 m braced post supplies the fluidization head (item 11b), and gravity supply from upstream is the site rule, with a treadle, hand or 12 V pump where that is impossible (item 12).

## Safety

> **Safety:** Rotating machinery. The bowl turns at up to 850 rpm in use with about 224 J of stored energy, and a rider can push it past the 900 rpm limit, because gearing does not cap the pedal speed; watch the speed display. Belts, chains and pulleys can trap fingers, hair and loose clothing. Never run without the lid guard and all belt and chain guards fitted. The bowl coasts for about 20 s after the drive stops: apply and park the brake, and wait for the bowl to stop, before opening the lid or flushing. The lid interlock pin must never be removed or bypassed. A full header tank 1.7 m up makes the machine top-heavy: fill it only with the machine standing level, never climb on the frame, and keep hoses from pulling sideways on the tank. Keep children and animals away from the machine. The bowl liner must be checked for cracks and debonding before every run; a failed liner at speed can throw fragments, and whether the tub and lid contain them has not been checked. The motor option adds stored electrical energy and a battery; follow the MotionCore safety section, and never bridge its emergency stop. MotionCore's stop does not brake, so the mechanical brake is still needed with the motor.

> **Safety:** Mercury. GravitySort must never be used with mercury, and it must not process tailings or concentrates from sites that used mercury without testing, because mercury contamination would spread through the bowl, the water and the table. Legacy mercury at a site calls for specialist handling through the partner organization.

> **Safety:** Water and slurry. Settling ponds and pits are drowning hazards and must be fenced. Slurry is slippery; wear boots with grip. Wash hands after handling concentrate; heavy minerals can contain arsenic (arsenopyrite) and lead.

> **Safety:** Smelting (outside this machine). Direct smelting reaches about 1,065 °C or more. Use a proper furnace, tongs, a face shield and ventilation, and never smelt indoors.

## Open questions

- [ ] Does a fluidized bowl of this size hold gold of 38 to 75 µm at 60 G with local feed, or is a larger bowl or higher G needed? (GVS-CAL-001 shows the particles reach the wall; bed behaviour needs testing.)
- [ ] Is a low-cost rotary union reliable in silty recirculated water, and does its seal drag stay near 0.10 N m?
- [ ] Can the cast polyurethane liner be made reliably in a small workshop, and how long does it last on quartz feed?
- [ ] Is a right-angle bevel gearbox easy to source, or should the bowl be driven by a quarter-turn belt (also a cost-down option)?
- [x] Water at a pedal-only site: gravity supply from upstream is the site rule for the first field trial; otherwise a bought treadle or hand pump worked in turns by the crew, or a small 12 V pump at sites with the MotionCore battery. Decided by Amish, 2026-10-02 (GVS-DEC-001).
- [ ] Concentrate security: padlock hasps on the concentrate box and the flush container (both now in the model and BOM) as the baseline, and a two-person rule for opening them proposed to the partner. Decided by Amish, 2026-10-02 (GVS-DEC-001); to be confirmed with the partner.
- [ ] Partner and country for the first field trial: Colombia, with a miners' cooperative introduced through the Alliance for Responsible Mining in Medellin as the first candidate to approach. Decided by Amish, 2026-10-02 (GVS-DEC-001).

## Key design decisions

Decision records are in [decisions/](decisions/). [GVS-DDR-001](decisions/0001-trl2-review-decisions.md) records the TRL 2 and TRL 3 review items. [GVS-DDR-002](decisions/0002-recommendations-accepted.md) records Amish's acceptance of the recommendations on 2026-09-25, what changed in the repo, and the items it left open, which Amish decided on 2026-10-02 (GVS-DEC-001). [GVS-DDR-003](decisions/0003-design-for-construction.md) records the design for construction, accepted by Amish on 2026-10-01 with its recommendations (R11 restated, the table bump stop, the pedal position). Open decisions are in the design decisions register, GVS-DEC-001 (`06-design-decisions.md`).

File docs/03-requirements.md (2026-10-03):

---
doc_id: GVS-REQ-001
title: GravitySort requirements
project: GravitySort
doc_type: Requirements
version: "1.0"
status: Draft
date: '2026-10-02'
author: Amish Chadha
license: CERN-OHL-S-2.0
revisions:
- version: "0.1"
  date: '2026-09-25'
  author: Amish Chadha
  change: Initial scaffold
- version: "0.2"
  date: '2026-09-25'
  author: Amish Chadha
  change: First measurable requirements for TRL 2, with status against the concept estimates
- version: "0.3"
  date: '2026-09-25'
  author: Amish Chadha
  change: TRL 3 status from GVS-CAL-001; R7 pack range aligned with MotionCore and GVS-DDR-001 item 6; MotionCore cost $335; proposed changes to R11 and R12 listed, awaiting Amish
- version: "0.4"
  date: '2026-09-25'
  author: Amish Chadha
  change: Recommendations accepted by Amish (DDR-002). R9 target $450; R12 restated for the pedal drive; R11 met with the lighter frame tube; status from GVS-CAL-001 v0.2
- version: "0.5"
  date: '2026-09-26'
  author: Amish Chadha
  change: Budget approved by Amish
- version: "0.6"
  date: '2026-10-01'
  author: Amish Chadha
  change: Status from GVS-CAL-001 v0.4 for the constructable design (GVS-DDR-003); R11 not met (95.7 kg, every load under 30 kg); R9 reported against the value-engineering target
- version: "0.7"
  date: '2026-10-01'
  author: Amish Chadha
  change: R11 restated by Amish (total 100 kg or less, loads 30 kg or less; GVS-DDR-003, A1); R11 met on paper
- version: "0.8"
  date: '2026-10-01'
  author: Amish Chadha
  change: Status from GVS-CAL-001 v0.6 with the table bump stop (GVS-DDR-003 A2); R9 $569 (USD 114 over the target); R11 met on paper at 96.5 kg
- version: "0.9"
  date: '2026-10-02'
  author: Amish Chadha
  change: "R2 restated as 200 kg/h of feed time (GVS-DEC-001, 2026-10-02); status updated"
- version: "1.0"
  date: '2026-10-02'
  author: Amish Chadha
  change: "Status from GVS-CAL-001 v0.8 with the 1.7 m braced tank post and the flush container (decisions of 2026-10-02): R9 $580 (USD 125 over the target), R11 99.3 kg, R12 lowest safety factor 16, R13 hasps on both containers; no status changed"
---

# GravitySort requirements

These are first-pass requirements for the concept. Targets are proposals for review, not user-validated needs, and will be revised after co-design sessions. At TRL 3 each has been checked by calculation or design review in GVS-CAL-001 v0.8, for the constructable design of GVS-DDR-003 (every part can be made and fixed to the next): none is unmet, two are at risk (R5, R6), two cannot be verified before testing (R4, R14) and nine are met on paper or by design review, R2 since its restatement by Amish on 2026-10-02 (GVS-DEC-001). R9 is reported against the value-engineering target: the constructable design is USD 125 over it. Recovery can only be verified by testing with real or spiked ore, which is TRL 4 work and on hold by Amish's instruction.

Table 1. Requirements. Status is from GVS-CAL-001 (`docs/04-calcs/results.csv`).

| ID | Requirement | Target | Verification (TRL 3 or later) | Status at TRL 3 (GVS-CAL-001) |
| --- | --- | --- | --- | --- |
| R1 | Use no mercury | No amalgamation step, no mercury-coated plates or traps, no step that needs mercury to recover gold from the concentrate | Design review of the flowsheet | Met (design review) |
| R2 | Process a small group's daily ore | 200 kg/h or more of feed time, of ore milled to below 2 mm, as slurry of 25 to 35 % solids: about 1.55 t in an eight-hour shift with three flush stops (restated on 2026-10-02, GVS-DEC-001; was 1.6 t per day) | Bowl capacity and cycle calculation | Met on paper: 200 kg/h of feed time; 1.55 t per shift after three 5 min flush stops |
| R3 | Hold fine gold in the bowl | Bowl acceleration adjustable from 40 to 80 G at the riffle rings (about 600 to 850 rpm at 100 mm radius), with speed shown to the operator | Drive ratio and speed calculation | Met on paper: 598 to 846 rpm at a 50 to 71 rpm cadence; speed display (BOM item 19) |
| R4 | Recover fine gold | Of free gold in the screened feed: 80 % or more of 75 to 1,000 µm gold and 50 % or more of 38 to 75 µm gold in the bowl concentrate; 60 % or more of all gold in the ore to smelted gold overall | Test with spiked or characterized ore (TRL 4) | **Not verifiable at TRL 3; at risk.** Settling check passes; bed behaviour needs testing |
| R5 | Make a concentrate that can be smelted without mercury | Bowl mass pull 0.5 % or less of feed; shaking table reduces one day's bowl concentrate (about 5 kg) to 100 g or less | Mass balance calculation; later test | **At risk:** bowl pull 0.33 % is met; 5.3 kg per day needs 53:1 on the table, likely two passes |
| R6 | Run on pedal power | Full throughput at 60 W or less at the pedals, at a cadence of 55 to 70 rpm | Power estimate from slurry, fluidization water and bearing losses | **At risk:** 48.2 W at 60 G is met; 62.8 W at 80 G is not; union seal drag assumed |
| R7 | Run on a small motor | Full throughput from the MotionCore 250 W reference drive on any 20 to 58 V pack that MotionCore accepts, with at least 3 times power margin | Power estimate | Met on paper: 5.2 times at 60 G, 4.0 times at 80 G; 0.55 kWh per shift |
| R8 | Use little water | 1.5 m3/h or less at 200 kg/h, and tolerate recirculated water with fine silt | Water balance calculation | Met on paper: 1.19 m3/h; a 3/4 in fluidization hose is needed, fed from the tank on its 1.7 m post (8.6 kPa at the union at mid-tank; GVS-CAL-001 section 6) |
| R9 | Keep parts cost near the value-engineering target | Value-engineering target $455 for parts, excluding the MotionCore module and battery: a hypothetical control target, not a limit (Amish, 2026-10-01; was $350, then $450; GVS-DDR-002) | Priced BOM | Estimated cost of the constructable design $580: **over the value-engineering target by USD 125** |
| R10 | Be built in a local workshop | Welding, drilling and hand tools only; no lathe; bowl liner cast in a printed mold | Design review of every part | Met (design review): set-screw bearing inserts, a taper bush and a welded nipple on a tube spindle avoid the lathe; liner cast on a six-segment printed core (GVS-DDR-003); casting route unproven |
| R11 | Travel to site | Breaks into loads of 30 kg or less, carried by two people; total 100 kg or less (restated from 80 kg by Amish, 2026-10-01; GVS-DDR-003, A1); assembled with hand tools in 30 min or less | Mass estimate from the model | Met on paper: 99.3 kg in six loads for the constructable design with the table bump stop, the 1.7 m braced tank post and the flush container (GVS-DDR-003; GVS-DEC-001), every load under 30 kg (heaviest 27.3 kg); 0.7 kg of margin; assembly time not verified |
| R12 | Guard every moving part | Bowl covered by a lid guard during running; belts, chains and the table head fully guarded; with the motor, bowl speed limited to 900 rpm or less by the drive ratio and the MotionCore speed limit; with the pedals, which gearing cannot cap, a burst safety factor of 10 or more for the bowl, jacket and rings at the highest reachable speed (1,200 rpm at a 100 rpm cadence) and the bowl speed shown to the rider; bowl stops within 15 s of stopping the drive (restated per GVS-DDR-002) | Design review, burst calculation and safety checklist | Met on paper: guards, lid interlock and a disc brake (0.6 s stop; about 20 s coasting); motor capped by its 1.2:1 step-up and the MotionCore limit; lowest pedal-case safety factor 16 at 1,200 rpm; speed display item 19. Containment of a liner fragment not verified |
| R13 | Clean up quickly and securely | Bowl concentrate flushed into a lockable container in 5 min or less without tools; table concentrate drops into a lockable tray | Design review; later timed trial | Met on paper: toolless lid clamps, lid lifts clear of the feed pipe; flush container and concentrate box each with a padlock hasp (GVS-DEC-001, 2026-10-02); time not verified |
| R14 | Last in abrasive service | Bowl liner and riffles replaceable in 30 min; liner life 500 h or more (estimate to be checked) | Wear data for cast polyurethane; later test | Not verifiable at TRL 3 |

## Assumptions

- Ore is milled to below 2 mm by the user's existing mill and screened on the GravitySort hopper screen.
- Free, liberated gold in the 38 to 1,000 µm range. Gold locked in sulfides or finer than about 20 µm is lost to tailings by any gravity method, so R4 applies to free gold only.
- Reference ore for the daily balance: 5 g/t, 1.6 t per day. Real grades vary widely (about 1 to 20 g/t).
- Healthy adult pedalling at 60 W or less for sessions of about 1 h, with operators taking turns.
- Budget: the $455 in `project.yaml` is a value-engineering target, a hypothetical control target and not a limit (Amish, 2026-10-01) (raised from $350 to $450 by Amish's decision of 2026-09-25 and to $455 on 2026-09-26, GVS-DDR-002) covers GravitySort parts. The MotionCore kit and reference motor ($335: $265 kit plus $70 motor, per MTC-CAL-001) and a battery are shared lab components, budgeted with MotionCore.
- The pack for the motor option is left to the user (GVS-DDR-001 item 6).

## Changes decided on 2026-09-25

Amish accepted the recommendations on 2026-09-25 (GVS-DDR-002):

- **R9:** target raised from $350 to $450 (item 1).
- **R12:** for the pedal drive, "limited to 900 rpm or less by gearing" is replaced by a burst safety factor of 10 or more at the highest reachable speed (1,200 rpm at a 100 rpm cadence) plus the speed display (item 9).
- **R11:** target unchanged at 80 kg; the frame, pedal outrigger and table stand move to 25 x 25 x 1.5 mm tube and the mass is re-estimated at 77.3 kg (item 10).

## Change decided on 2026-09-26

- **R9:** target raised from $450 to $455 to cover the priced BOM (budget approved by Amish, GVS-DDR-002). Not met to met on paper.

## Change decided on 2026-10-01

Amish, 2026-10-01: "i agree with your recommendations for both GrowRider and GravitySort" (GVS-DDR-003, A1; GVS-DEC-001):

- **R11:** total restated from 80 kg or less to 100 kg or less, keeping every load at 30 kg or less, because the per-load limit decides whether two people can carry the machine to site. Not met to met on paper (95.7 kg). The savings of about 16 kg are to be tried at TRL 4.

## Change decided on 2026-10-02

Amish, 2026-10-02: "i approve your recommendations for all 555 open decisions." (GVS-DDR-001 item 13; GVS-DEC-001):

- **R2:** restated as 200 kg/h of feed time, about 1.55 t in an eight-hour shift with three flush stops; the design feed stays at 200 kg/h rather than rising to 210 kg/h, which would load the bowl and table harder while R5 and R6 are at risk. At risk to met on paper.

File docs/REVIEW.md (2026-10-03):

# Review note: GravitySort

## Session 2026-10-02: Photoreal renders redone on the constructable design

Amish, 2026-10-02: "Photoreal renders are out of date in most repos ... COMPLETE THESE". Rendered with Blender Cycles on Amish's Mac (batch F1) from the scenes exported from `cad/src/product_model.py`, captioned with `.kit/photo_caption.py`; `media/card.png` and `media/social-preview.png` regenerated with `.kit/cards.py`. Each raw render was looked at once. No commit or push; `trl` unchanged.

- Views: `media/render-hero.png`, `media/render-exploded.png`, `media/render-detail.png`.
- Re-render: exploded, once. In the first render the flush container (BOM item 23) overlapped the table belt guard (item 11), because `model.py`'s exploded offsets move both forward into the same space. `cad/src/product_model.py` now uses `model.py`'s offsets except item 23, moved 600 mm forward instead of 300 mm, so the container clears the guard; scenes re-exported. `model.py` and the concept exploded view are unchanged.
- Appearance deviations already logged (2026-10-02, open item 2, Proposed, awaiting Amish): crank render pose with level pedals; tank label and bung caps; speed display screen and readout; brass padlock on the flush container hasp; tailings hose to the pond; patch of ground; seated clay mannequin with its feet on the pedals. Unchanged.
- `python3 .kit/image_qc.py`: 5 images, 0 problems. `python3 .kit/render.py --check`: no FAIL, no storefront warning.
- The two stale-render notes (sessions of 2026-10-01) are removed; this work resolves them.

## Session 2026-10-02: approved follow-ups carried out

Amish, 2026-10-02, approved carrying out every follow-up action from the open-decision sign-off ("APPROVED CHANGES, COMPLETE THESE") and preparing the render scenes. This session carried the decisions of 2026-10-02 (GVS-DEC-001) into the model, BOM, calculations, drawings, pictures and build plan. trl stays 3; no build or test work was done; no commit or push (no git in this copy).

### Follow-ups

| # | Follow-up (2026-10-02 list) | Done | What was done |
| --- | --- | --- | --- |
| 1 | Raise the tank post to 1.7 m with a brace; regenerate GVS-DWG-001 and the frame and header tank sketches | Done | `cad/src/model.py`: cradle at 1,700 mm, post 995 mm, two braces of the frame tube (717 mm cut length) from 1,350 mm up the post to the front and back top side rails, 250 mm toward the table end. To keep a full tank from tipping the taller machine, the post moved from 180 mm behind the centre line onto it (see Decisions proposed). The hose's short run to the rotameter rises from 840 to 860 mm to clear the bracket. Six checks added; 126 of 126 pass. STEP and STL regenerated. GVS-DWG-001 Rev P5; GVS-DWG-101 Rev P2; frame cut picture and joint 8 redrawn. There is no separate header tank sketch (the drum is bought); the cradle is on GVS-DWG-101 |
| 2 | Build plan frame step (3.1, item 7) and step 13, text and pictures | Done | GVS-BLD-001 v0.4: section 3.1 item 7 and check, step 13 (lift the drum empty, hose route), joint 8 under step 13, section 1 and Table 1 (water row), first checks (tank on its post, flush container lock), safety stop S8 (tipping). Overview and all 19 step pictures redrawn, since the frame shows in nearly all of them |
| 3 | Longer post tube and brace in the frame BOM line, repriced | Done | Line 1: 16.4 m of tube, $43 to $47 (1.9 m more tube at about $1.80/m plus welding) |
| 4 | Re-run sizing.py: head at the union, mass (R11), tipping check | Done | GVS-CAL-001 v0.8. Union 8.6 kPa at mid-tank against 8.1 kPa needed (7.1 to 10.1 kPa from nearly empty to nearly full; lowest ring still 9.0 kPa net at 600 rpm with the tank nearly empty). Mass 99.3 kg, heaviest load 27.3 kg. Tipping: 13.5 degrees sideways with a full tank (193 N push at the tank); post above the braces safety factor 2.3 at that push; braces 543 N, buckling factor 81 |
| 5 | Gravity-supply site rule and pump fallbacks into the field trial plan at TRL 4 | Not done | A field trial plan is TRL 4 work, on hold under the TRL 3 cap (CLAUDE.md section 1). The rule is in GVS-PRC-001, GVS-CAL-001 section 4 and the BOM notes, ready to carry over when TRL 4 opens |
| 6 | Approach the Alliance for Responsible Mining in Medellin | Not done | An outreach action for Amish, not repo work; nothing has been agreed or sent |
| 7 | Padlock hasp on the flush container in the model and BOM; propose the two-person rule | Done (model, BOM); proposal is Amish's | Flush container (10 L HDPE pail, lid, hasp staple and strap) added to the model, loose on the ground in front of the tub; three checks; BOM line 23, $7; build plan section 3.21 with Figure 38 (joint 16). Proposing the two-person rule to the partner waits for a partner |

### Documents changed and new versions

- `cad/src/model.py`, STEP and STL in `cad/step/`, `cad/stl/` (126 checks, all pass)
- `cad/src/sheets.py`, `cad/drawings/GVS-DWG-001` Rev P5 (loose flush container left off the views; listed in the notes)
- `cad/src/build_plan_media.py`, `cad/drawings/GVS-DWG-101` Rev P2; `docs/05-build-plan/overview.png`, `frame-cuts.png`, `joint-08.png`, new `joint-16.png`, `step-01.png` to `step-19.png`
- `cad/src/concept_media.py`, `media/hero.png`, `concept-blueprint` (GVS-DWG-010 Rev P4), `exploded.png`, `cutaway.png`, `flow.png`, `model.glb`, `viewer.html`
- `cad/src/product_model.py` (rebuilt; see below)
- `bom/bom.csv` (line 1 repriced, line 23 added), `bom/bom-notes.md`
- `docs/04-calcs/sizing.py`, `results.csv`, `01-sizing.md` GVS-CAL-001 v0.8
- `docs/03-requirements.md` GVS-REQ-001 v1.0; `docs/02-concept.md` GVS-PRC-001 v1.0; `docs/05-build-plan.md` GVS-BLD-001 v0.4; `docs/06-design-decisions.md` GVS-DEC-001 v0.6; `docs/decisions/0003-design-for-construction.md` GVS-DDR-003 v0.5; `README.md`
- PDFs regenerated with `python3 .kit/render.py`

### Key results

- Requirement status: none changed. R2 stays met on paper (already restated in v0.9); R11 met on paper at 99.3 kg with only 0.7 kg to spare; R12 met with its lowest burst safety factor down from 17 to 16 (the higher head raises the jacket pressure); R13 now has a hasp on both containers; R9 over the value-engineering target.
- Value-engineering target: USD 455. Estimated cost of the constructable design: USD 580 (USD 125 over the target).
- Mass 99.3 kg in six loads, heaviest 27.3 kg (the frame). Overall size 2.78 x 0.79 x 2.10 m (was 1.65 m tall).
- Fluidization holes: with the higher head, 12 L/min needs only about 74 holes of 1.0 mm with the valve fully open. The 89 graded holes decided under GVS-DDR-002 are kept; the valve is then set slightly closed, which leaves margin as the tank level falls.
- The hose length in the calculation now comes from the model's route (2.31 m plus 0.5 m of slack, 2.8 m) instead of the 4 m allowance; with 4 m the union would have 8.1 kPa, just at the need.

### Decisions proposed, awaiting Amish

1. **Tank post on the centre line and the tipping criterion** (now open item 1 in GVS-DEC-001). Raising the post where it stood, 180 mm behind the centre line, would let a full tank tip the machine sideways on a 9.5 degree slope (133 N push at the tank); on the centre line it is 13.5 degrees (193 N), better than the old 1.25 m layout (11.6 degrees). The check uses a 10 degree slope in any direction as its reading of "cannot tip it". Options: (a) keep as made; (b) back to 180 mm behind with wider feet at the back; (c) a stricter criterion with wider feet. Recommendation: (a).
2. **Appearance model deviations from `model.py`** (STANDARDS section 12): the cranks drawn at 100 degrees from top dead centre with level pedals (render pose, decided 2026-10-01); a label and bung caps on the tank; the speed display's screen and readout; a brass padlock on the flush container hasp (padlocks are the partner's, not in the BOM); a tailings hose from the tailings pipe to the pond; a patch of ground; the seated clay mannequin. Recommendation: accept as appearance detail. The previous appearance model's lid sight window is gone (the plain lid was decided on 2026-10-01), as are its concept table stand, launder position and hose route.

### Points for Amish

- The tank top is now 2.1 m up, so gravity supply needs a source more than about 2.1 m above the machine's feet, and a pump lifts about 2.1 m (6.8 W hydraulic).
- With the post welded on, the frame load is about 1.7 m tall for transport. A socket so the post and braces bolt on is a possible later change (suggestion only).
- R11 has 0.7 kg of margin; any further addition will need one of the savings in GVS-DDR-003 A1 (b).

### Cross-repo actions

None. No follow-up in this list lives in another repo.

### Render scenes

`cad/src/product_model.py` was rebuilt so that every part is taken from `build_components()` in `model.py` (so it matches the constructable design, the 1.7 m braced post and the flush container), with product colours and materials, the crank render pose and the appearance details above. RENDER_VIEWS kept: hero, exploded, detail. Scenes exported with `python3 .kit/export_views.py /home/claude/renders/gravitysort`. Photoreal renders, `media/card.png` and `media/social-preview.png` were not regenerated; they are made on Amish's Mac next.

### Safety

A full header tank 1.7 m up makes the machine top-heavy: about 190 N pushed sideways at the tank tips it on level ground. The calculation note, precis and build plan (safety stop S8) now say to fill the tank only with the machine level, lift the drum onto the cradle empty, and never climb on the frame or hang anything on the tank. Other safety notes are unchanged.

### Recommended next step

Amish to decide open item 1 in GVS-DEC-001, then render the photoreal set and cards on the Mac from the exported scenes.

## Session 2026-10-02: open decisions decided

Amish, 2026-10-02: "i approve your recommendations for all 555 open decisions." The recommendations written for this repo's open decisions are recorded as decided.

### Decisions recorded

5 decisions, moved from "Open decisions" to "Decisions made" in the register (GVS-DEC-001 v0.5):

1. Fluidization head: the header tank post rises to 1.7 m, braced so a full 60 L tank cannot tip it (GVS-DDR-001 item 11b).
2. Site water: gravity supply from upstream is the site rule for the first field trial; otherwise a treadle or hand pump worked in turns, or a 12 V pump at sites with the MotionCore battery (item 12).
3. R2 restated as 200 kg/h of feed time, about 1.55 t per eight-hour shift with three flush stops; design feed kept at 200 kg/h (item 13).
4. First partner: Colombia, with a miners' cooperative introduced through the Alliance for Responsible Mining in Medellin as the first candidate to approach (item 8b).
5. Concentrate security: padlock hasps on the concentrate box and the flush container, and a two-person rule proposed; both to be confirmed with the partner.

### Documents changed

- `docs/06-design-decisions.md`: GVS-DEC-001 v0.5
- `docs/decisions/0001-trl2-review-decisions.md`: GVS-DDR-001 v0.3
- `docs/decisions/0002-recommendations-accepted.md`: GVS-DDR-002 v0.3
- `docs/01-problem.md`: GVS-PRB-001 v0.7 (site water, partner)
- `docs/02-concept.md`: GVS-PRC-001 v0.9 (header post, water, R2, security, partner)
- `docs/03-requirements.md`: GVS-REQ-001 v0.9 (R2 restated; met on paper)
- `docs/04-calcs/01-sizing.md`: GVS-CAL-001 v0.7 (R2 status; head and water decisions; summary corrected on the 1.25 m post; no figure changed)
- `bom/bom-notes.md` (not controlled)

### Follow-up actions to carry approved decisions into the design

1. Decision 1: raise the tank post in `cad/src/model.py` from 1.25 m to 1.7 m with a brace so a full 60 L tank cannot tip it, and regenerate GVS-DWG-001 and the frame and header tank making sketches (model, drawings).
2. Decision 1: update the build plan frame step (section 3.1, item 7, tank post 545) and step 13 (header tank) text and pictures for the 1.7 m braced post (pictures).
3. Decision 1: add the longer post tube and the brace to the frame line of the BOM and reprice it (BOM).
4. Decision 1: re-run `docs/04-calcs/sizing.py` for the 1.7 m post: head at the union (target 8.1 kPa), mass (R11), and a tipping check of the post with a full tank (calculations).
5. Decision 2: write the gravity-supply site rule and the pump fallbacks into the field trial plan when TRL 4 is opened; no machine change (docs).
6. Decision 4: approach the Alliance for Responsible Mining in Medellin to be introduced to a miners' cooperative; nothing is agreed (docs).
7. Decision 5: add a padlock hasp to the flush container in the model and BOM (the concentrate box already has one), and propose the two-person rule to the partner (model, BOM).

### Points found in the review

- The decisions-made row for R11 says the design is 95.7 kg; with the bump stop it is 96.5 kg (calculation note v0.6), 3.5 kg under the restated 100 kg. A 1.7 m post (item 1) adds a little more.
- The calculation note summary said 'the fluidization supply only works with a 3/4 in hose from the 1.25 m header post', but section 6 shows that post gives 3.7 kPa against the 8.1 kPa needed, so it does not work without item 1. The summary is corrected in GVS-CAL-001 v0.7.
- Cost is $569 against the $455 target, $114 (25 percent) over, excluding the MotionCore kit, motor and battery.

## Session 2026-10-01: bump stop change accepted

Amish, 2026-10-01: "I approve of your recommendations for PicoFlow and GravitySort". For GravitySort this accepts the change made while adding the table bump stop, which was recorded in GVS-DDR-003 Table 2 and left open for his review (session "table bump stop in the model, drawings and build plan", below). It was not an open item in the register, so it is added to Decisions made only. No design change; trl stays 3; no build or test work was done.

### Accepted, as made

| Item | Decision |
| --- | --- |
| GVS-DDR-003, Table 2, "Table bump stop" | The pitman pin works in a 12 x 20 mm slot in the deck cheeks (8 mm of free play), and the plywood legs are set leaning about 5 mm so they press the deck on the buffer with about 200 N, so the deck can strike the stop and the stroke is asymmetric |

### What changed

- `docs/decisions/0003-design-for-construction.md` (GVS-DDR-003 v0.4): status line records the acceptance with Amish's words; the Table 2 row is marked accepted; a consequence states the slot and leaning legs as the design and the toggle head as the fallback.
- `docs/06-design-decisions.md` (GVS-DEC-001 v0.4): a Decisions made row dated 2026-10-01 with Amish's words and the record. The open decisions (1 to 5) and the items to confirm are unchanged.
- PDFs regenerated with `python3 .kit/render.py`.

No model, BOM, calculation, drawing or build plan change: the slot and the legs were already drawn and costed (mass 96.5 kg, USD 569, USD 114 over the USD 455 value-engineering target). Requirement status is unchanged.

### Still open (GVS-DEC-001)

1. Head for the fluidization supply.
2. Water from the settling pond at pedal-only sites.
3. R2 throughput margin.
4. First co-design partner and country.
5. Concentrate security in practice.

### Safety

Unchanged. The striker and buffer close with up to about 600 N at every stroke; set the stop only with the table belt slack and the head turned by hand (build plan section 3.16, safety stop S7).

### Recommended next step

Re-render the photoreal set and cards on the Mac so they show the bump stop. The stop setting, leg lean and buffer rate are tuned in the first table test, which is TRL 4 work and on hold under the TRL 3 cap.

## Session 2026-10-01: table bump stop in the model, drawings and build plan

Amish asked: "gravitysort - update the documentation, CAD work and picture renderings", to carry out the bump stop he accepted earlier the same day (GVS-DDR-003, A2; register, Decisions made).

### What was done

- **Design.** The stop sits at the return end, the far end of the forward stroke where the deck turns back toward the head, because gold walks toward the concentrate box only if the deck stops sharply while moving that way. Parts: a stop bracket (25 x 25 x 1.5 mm tube arm 244 long, 40 x 66 x 6 mm foot bolted on top of the frame's table-end top rail 205 mm behind the centre line with two M8, 40 x 61 x 6 mm upright); a bought rubber buffer 40 mm across and 30 mm long, about 55 Shore A, M8 female thread, rated 800 N or more, on an M8 stud 45 long with a lock nut each side of the upright; a 6 mm steel striker angle (40 wide, legs 40 and 70) screwed under the deck's head end at its back edge. Setting: zero where the buffer just touches at full forward travel, 3 mm in to start, 2 to 6 mm useful, 0 to 8 mm available. The nuts are reached with a 13 mm spanner from behind the machine.
- **Knock-on change needed to make the stop work.** A rigid pitman drags the deck through the whole circle of the eccentric, so it can never strike anything. The pitman pin now works in a 12 x 20 mm slot in the deck cheeks (8 mm of free play toward the far end), and the plywood legs are set leaning about 5 mm so they press the deck on the buffer with about 200 N. The pin pulls the deck toward the head; the legs push it forward into the stop. This keeps the accepted option (a) and the concept's "spring return"; it is recorded in GVS-DDR-003 Table 2. Amish may want to note it, since it is a second part of the table changed for the stop.
- `cad/src/model.py`: stop bracket, buffer with stud and nuts, striker, and the cheek slot; 13 new checks (contacts, 15 mm clearance at the head end of the stroke, clear of the legs, deck, head and pitman, spanner room); **115 of 115 pass**. STEP and STL re-exported.
- `docs/04-calcs/sizing.py`, `results.csv`, `docs/04-calcs/01-sizing.md` (GVS-CAL-001 v0.6): section 9 sizes the stop (Table 4); mass and cost updated.
- `bom/bom.csv`: line 21 (bracket and striker, make, $6) and line 22 (buffer, stud and fixings, buy, $5); `bom/bom-notes.md` updated.
- `cad/src/build_plan_media.py`: new making sketch GVS-DWG-121 (bracket and striker), new joint 15 (the stop), step 16 redrawn with the stop, steps 17 and 18 and the overview redrawn (the stop is in group 22); sketches GVS-DWG-114 (cheek slot), 116 and 117 to Rev P2; joint 10 subtitle.
- `cad/src/sheets.py`: general arrangement GVS-DWG-001 to Rev P4. `cad/src/concept_media.py`: concept media regenerated (blueprint GVS-DWG-010 Rev P3; the stop is item 21 in the exploded view).
- `docs/05-build-plan.md` (GVS-BLD-001 v0.3): section 2 row, section 3.15 (slot), section 3.16 (making, fitting and setting the stop, with Figures 29 and 30), 3.17 check, bought buffer, step 14 and step 16, a first check for the stop, safety stop S7 (before the table runs); figures renumbered.
- `docs/02-concept.md` (GVS-PRC-001 v0.8): component 15 and new row 21, 22; mass and cost. `docs/03-requirements.md` (GVS-REQ-001 v0.8): R9 and R11 values. `docs/decisions/0003-design-for-construction.md` (GVS-DDR-003 v0.3): A2 carried out. `docs/06-design-decisions.md` (GVS-DEC-001 v0.3): follow-up note removed, buffer added to the items to confirm, Value engineering updated. `README.md`: mass and cost.
- `cad/src/product_model.py`: the bump stop added (bracket, buffer, stud and nuts, striker) at the model's positions; the file builds (97 parts).

### Key results

- Bump stop at 270 strokes/min, 17 kg moving, set 3 mm in: stroke 12 mm, strike at 0.17 m/s, **0.24 J per stroke** (1.1 W), buffer squeezed 3.2 mm (11 %, limit 20 %), 539 N peak, **2.1 G at the stop against 0.6 G at the head end (3.4 times)**. Across 2 to 6 mm: 0.18 to 0.37 J, 3.1 to 3.9 times, peak force under 600 N, pin pull at most 593 N.
- Mass **96.5 kg** (was 95.7), heaviest load 25.2 kg: R11 still met on paper.
- Value-engineering target: USD 455. Estimated cost of the constructable design: USD 569 (USD 114 over the target).
- Requirements unchanged otherwise: none unmet; R2, R5, R6 at risk; R4, R14 not verifiable at TRL 3.

### Decisions proposed and awaiting Amish

- None new. The cheek slot and the leaning legs are how the accepted stop is made to work, not a new choice; if Amish prefers, the toggle head (A2, option b) remains the fallback.

### Safety

- The striker and buffer close with up to about 600 N at every stroke: a pinch point. The plan says to set the stop only with the table belt slack and the head turned by hand (section 3.16, safety stop S7). The stop is outside the table belt guard, under the deck's back edge.

### Recommended next step

- Re-render the photoreal set and cards on the Mac. The stop setting (2 to 6 mm), leg stiffness and buffer rate are estimates to be tuned in the first table test, which is TRL 4 work and on hold under the TRL 3 cap.

## Session 2026-10-01: recommendations accepted

Amish, 2026-10-01: "i agree with your recommendations for both GrowRider and GravitySort". This answers the recommendations in the design decisions register (GVS-DEC-001 v0.1), including GVS-DDR-003. Items whose recommendation was "None yet" or "Decide with the partner" were not decided and stay open. trl stays 3; no build or test work was done.

### Accepted, as recommended

| Register item (v0.1) | Decision |
| --- | --- |
| 1 | GVS-DDR-003 accepted: design-for-construction changes P1 to P15 and their knock-on changes |
| 2 | R11 restated: total 100 kg or less, every load 30 kg or less (was 80 kg in all); try the savings of about 16 kg at TRL 4 |
| 3 | Asymmetric table stroke: adjustable rubber bump stop at the return end for the prototype; a toggle head only if the first test shows it is not enough |
| 4 | Pedal position: keep the bicycle-style seat, seat post adjustable; check with two riders at TRL 4 |
| 9 | Liner fragment containment: check by calculation before any spin test; add a steel band round the tub only if the check fails |
| 10 | Lid: keep the plain 10 mm HDPE lid, no sight window |
| 12 | Cranks at 100 degrees from top dead centre is a render pose only |

### What changed

- `docs/06-design-decisions.md` (GVS-DEC-001 v0.2): the seven items moved to Decisions made, dated 2026-10-01, with Amish's words and the record; open items renumbered 1 to 5.
- `docs/decisions/0003-design-for-construction.md` (GVS-DDR-003 v0.2, status Draft as for the pilot repos): status line now "accepted" with Amish's words; Table 3 marked as accepted as recommended; a consequence added for A1 to A3.
- `docs/03-requirements.md` (GVS-REQ-001 v0.7): R11 restated to 100 kg or less in all, loads 30 kg or less; status not met to **met on paper** (95.7 kg, heaviest load 25.2 kg); a "Change decided on 2026-10-01" section added; R11 removed from "Still proposed".
- `docs/04-calcs/sizing.py` and `docs/04-calcs/results.csv`: the R11 check uses 100 kg; re-run, and only the R11 row changed.
- `docs/04-calcs/01-sizing.md` (GVS-CAL-001 v0.5): summary, section 11 and Table 6 show R11 met on paper against the restated total.
- `docs/02-concept.md` (GVS-PRC-001 v0.7): summary and the size and mass row show R11 met on paper; component 15 records the bump stop decision; the decision records paragraph names GVS-DDR-003 and the register.
- `docs/05-build-plan.md` (GVS-BLD-001 v0.2): section 2 says GVS-DDR-003 is accepted. No open decisions were added.
- PDFs regenerated for GVS-DEC-001 v0.2, GVS-DDR-003 v0.2, GVS-REQ-001 v0.7, GVS-CAL-001 v0.5, GVS-PRC-001 v0.7 and GVS-BLD-001 v0.2; the superseded PDFs removed.

Requirements (GVS-CAL-001 v0.5): none unmet, three at risk (R2, R5, R6), two not verifiable at TRL 3 (R4, R14), eight met on paper or by design review; R9 is USD 103 over the value-engineering target.

### Still to do for the accepted decisions

- The rubber bump stop is not yet in the model, the making sketches or the build plan (section 3.16 and step 16 would carry it). Adding it needs a model change, a regenerated picture set and a first check for the stroke; it is left for the next design session.
- The containment calculation (decided item 9) is still to be done; safety stop S4 of the build plan already requires it before any spin above hand speed.

### Still open (GVS-DEC-001)

1. Head for the fluidization supply (1.7 m tank post or a small pump).
2. Water from the settling pond at pedal-only sites.
3. R2 throughput margin.
4. First co-design partner and country.
5. Concentrate security in practice.

The 10 items to confirm when parts are bought are unchanged.

### Recommended next step

Add the rubber bump stop to the model and the build plan, and do the containment calculation, once Amish asks for that session. Regenerate the product renders on the Mac. TRL 4 remains on hold by Amish's instruction.

## Session 2026-10-01: prototype build plan and design for construction (kit 1.7.0)

Kit 1.7.0 installed (`.kit/`, `.claude/commands/`, root `CLAUDE.md` from `.kit/CLAUDE.md`). The design was made constructable under Amish's 2026-09-30 instruction ("If you are realising that the design cannot be built as per concept - fix the design assumptions to match and be physically feasible as you draw the illustrations."), and the illustrated build plan and the design decisions register were written. Every change is in `docs/decisions/0003-design-for-construction.md` (GVS-DDR-003, Draft, open for Amish's review).

### Design changes made for construction

1. Frame: the low stretchers become lower side rails (255 mm up); the gearbox and spindle members lie in pairs on top of them, either side of each vertical shaft (the concept's members floated, and two were crossed by the spindle and the gearbox shaft); tub members hang on four drop posts; end post, low end member and head member added. 14.5 m of tube (was 11.75 m).
2. Bearings: 150 x 130 x 6 mm plates welded under the spindle pair and the tub pair; the flanged bearings hang under them (centres 255 and 420 mm, 165 mm apart).
3. Spindle: 25 x 2 mm stainless tube carrying the fluidization water, with a 1/2 in BSP nipple welded in its foot (was a solid shaft); first critical speed 2,710 rpm (2.3 times the sprint speed).
4. Bowl fixing: pinned 25 mm bore flange hub, four M6 bolts with 12 mm spacers into nuts cast in the liner; bonded closing ring at the jacket top (the jacket was open).
5. Liner core printed in six segments round a key (the riffle rings are undercuts).
6. Tub: 63 mm standpipe in a rubber grommet over the upper bearing; 75 mm tailings pipe through a rubber grommet in the back wall (the launder box ran through an uncut wall and into the frame); four M8 floor bolts.
7. Feed pipe stops 15 mm above the lid, so the lid lifts off; hopper bottom opened; hopper sits in a ring on a support post bolted to the front top rail.
8. Pedal drive: bottom bracket at 438 mm, 100 mm above the jackshaft (338 mm, on pillow blocks on the gearbox pair), so the chain clears the frame; outrigger detailed and bolted to the frame end by two plates; saddle about 910 to 960 mm.
9. Gearbox stands across the gearbox pair; its output shaft goes down between them.
10. Table belt plane moved outside the frame front (the take-off pulley hit the members and the belt looped round a frame rail).
11. Motor option on a bolt-on cradle behind the frame (the hub motor enclosed its chain).
12. Guards: bowl belt guard on hangers, chain case seated on the gearbox member, table belt guard added (safety note of 2026-09-26).
13. Water: tank post and cradle drawn; valve on the back of the drum; rotameter on a bracket on the back top rail; hose down the back of the frame to the union (it ran through the drive pulley).
14. Table: plywood flexure legs on a welded base; head plate and shelf bolted to the frame end with pillow blocks, eccentric (15 mm stroke) and pitman; latched belt tensioner as the clutch; tailings launder under the front edge; lockable concentrate box under the far end; wash water pipe.
15. Speed display and brake lever moved to the pedal-end top rail facing the rider; caliper on an L bracket on the spindle member; disc on a flange welded to a shaft collar.

`cad/src/model.py` now models every component and runs 102 constructability checks (`python cad/src/model.py --check`); all pass.

### Files

- `cad/src/model.py` (rewritten: `build_components()`, `checks()`), `cad/src/build_plan_media.py` (new), `cad/src/sheets.py` (GVS-DWG-001 Rev P2 to **P3**), `cad/src/concept_media.py` (key figures, blueprint GVS-DWG-010 P2); STEP and STL re-exported; `media/` concept media regenerated.
- `docs/05-build-plan.md` (GVS-BLD-001 v0.1) with pictures in `docs/05-build-plan/` (overview, frame cut list, 14 joints, 19 steps) and making sketches `cad/drawings/GVS-DWG-101` to `120` (20 sheets).
- `docs/06-design-decisions.md` (GVS-DEC-001 v0.1): 12 open decisions, 10 items to confirm when parts are bought, a Value engineering section, 7 decisions made.
- `docs/decisions/0003-design-for-construction.md` (GVS-DDR-003 v0.1, Draft).
- GVS-CAL-001 v0.4 and `docs/04-calcs/sizing.py` (hollow spindle, new masses, cost against the value-engineering target; `results.csv` regenerated); GVS-REQ-001 v0.6; GVS-PRC-001 v0.6; GVS-PRB-001 v0.6 (budget wording); `bom/bom.csv` (lines 1 to 4, 6, 8, 10, 11, 13 to 19 updated, line 20 added) and `bom/bom-notes.md`; `project.yaml` (`design_state: constructable`, three documents added to `trl_evidence`; `budget_usd` unchanged); `README.md` (links line, budget line, concept figures, "Building the prototype" section).

### Key results

- **R11 not met:** 95.7 kg in six loads against 80 kg (16 kg over); every load is under 30 kg, heaviest 25.2 kg. The concept's 77.3 kg left out several parts and joints.
- **Cost:** Value-engineering target: USD 455. Estimated cost of the constructable design: USD 558 (USD 103 over the target).
- Requirements (GVS-CAL-001 v0.4): one not met (R11), three at risk (R2, R5, R6), two not verifiable at TRL 3 (R4, R14), seven met on paper or by design review; R9 reported against the value-engineering target.
- Unchanged: bowl speed and G, drive ratio, power, water, settling, fluidization supply, burst factors, brake stop time, gold balance.

### Proposed, awaiting Amish

All open items are in the design decisions register (GVS-DEC-001). New this session: accept GVS-DDR-003 (open decision 1); R11 total mass (2: recommend restating the total as 100 kg, keeping loads of 30 kg or less); how to make the table stroke asymmetric (3: recommend an adjustable bump stop); pedal position for different riders (4). Carried over: fluidization head, water pumping, R2 margin, first partner, liner fragment containment, lid window, concentrate security, render crank pose.

### Safety

- The table belt now has a guard; every belt, chain and pulley is guarded in the model.
- The standpipe keeps spilt slurry off the upper bearing.
- Containment of a liner fragment by the tub and lid is still not checked (register item 9); the build plan's safety stop S4 requires it before any spin above hand speed.
- The pedal drive is still not speed-capped; the speed display and the burst margin carry that risk (R12 as restated).

### Recommended next step

Amish to review GVS-DDR-003 and the open decisions in GVS-DEC-001, in particular R11 (2) and the table stroke (3). Then regenerate the product renders on the Mac. TRL 4 (building to the plan) stays on hold.

## Session 2026-09-26: budget approved

Amish wrote, in chat on 2026-09-26: "i approve all the budget items." The open budget item (the $5 gap on R9) is decided: budget set to $455 to cover the priced BOM (GVS-DDR-002 v0.2).

- `project.yaml` `budget_usd` $450 to $455; README budget and cost lines updated.
- R9 target $450 to $455; status **not met to met on paper**, with no margin ($455 BOM, MotionCore and battery excluded).
- Requirement counts (GVS-CAL-001 v0.3): none not met, three at risk, two not verifiable, nine met on paper.
- Documents: GVS-PRB-001 v0.5, GVS-PRC-001 v0.5, GVS-REQ-001 v0.5, GVS-CAL-001 v0.3 (`sizing.py` budget constant 450 to 455, script re-run, `results.csv` regenerated), GVS-DDR-002 v0.2; `bom/bom-notes.md`; PDFs rebuilt. No media shows the budget, so none was regenerated.

## Session 2026-09-25: recommendations accepted

Amish wrote on 2026-09-25: "i accept all your recommendations, go with them across all repos." Every item with a recommendation is now **Decided by Amish, 2026-09-25: go with recommendation**, recorded in `docs/decisions/0002-recommendations-accepted.md` (GVS-DDR-002 v0.1). GVS-DDR-001 moves to v0.2 with its statuses updated.

### Decisions applied and what changed

| Item | Decision | Before | After |
| --- | --- | --- | --- |
| 1 | Budget | `budget_usd` $350 | `budget_usd` $450; R9 target $450; BOM $465 to $455 |
| 9 | R12 restated for the pedal drive: burst safety factor 10 or more at 1,200 rpm plus the speed display, instead of a gearing cap | R12 not met as written | R12 met on paper (lowest factor 17) |
| 10 | Frame, pedal outrigger, table stretchers and head post in 25 x 25 x 1.5 mm tube, then re-estimate | 30 x 30 x 2 mm; 88.3 kg, heaviest load 25.8 kg | 77.3 kg, heaviest load 18.1 kg; R11 met on paper. New frame member check: 61 MPa, safety factor 3.9, 0.73 mm deflection |
| 11a | 3/4 in fluidization hose and about 89 graded 1.0 mm holes | Engineering proposal | Decided; no geometry change |
| 14 | Disc brake with parking latch and lid pin, bicycle computer display, 1.2:1 motor step-up, MotionCore lid switch | Engineering proposals | Decided; no geometry change |
| 2 to 7, 8a | Two stages; fluidized bowl; cast PU liner; pedal baseline with MotionCore option; battery left to the user; borax smelting; partner screening criterion | Adopted for TRL 3, open for review | Decided; wording only |

Files changed: `project.yaml` (budget, DDR-002 in the evidence list); `README.md` (budget, concept numbers, DDR-002 link, safety line, new "What sparked the idea"); `cad/src/model.py` (`tube` 25, `tube_wall` 1.5; cross members and table stretchers follow the tube size) with STEP and STL re-exported; `cad/src/sheets.py` and GVS-DWG-001 Rev P1 to **P2**; `cad/src/concept_media.py` key figure (77 kg) and all of `media/` regenerated; `bom/bom.csv` items 1 ($40 to $32) and 15 ($30 to $28); `bom/bom-notes.md`; `docs/04-calcs/sizing.py` and `results.csv`; GVS-CAL-001 v0.1 to v0.2; GVS-REQ-001, GVS-PRC-001 and GVS-PRB-001 v0.3 to v0.4; GVS-DDR-001 v0.1 to v0.2. The pitch and problem in `project.yaml` are unchanged (no rewording was recommended). `docs/01-problem.md` did not attribute the idea to any ideation session.

The README "What sparked the idea" section now traces the design to the Minamata Convention's call to eliminate whole-ore amalgamation (NRDC summary cited). All drawings, media and PDFs were regenerated with designmolecule.com; superseded PDFs in `docs/pdf/` were removed where they still carried the old domain.

### Requirement status (GVS-CAL-001 v0.2)

| ID | Status | Value |
| --- | --- | --- |
| R9 | **Not met** | $455 against $450 ($5, 1.1 % over) |
| R2 | At risk | 1.55 t per shift after three flush stops; 1.6 t needs 206 kg/h |
| R5 | At risk | Bowl pull 0.33 % met; 5.3 kg per day needs 53:1 on the table, likely two passes |
| R6 | At risk | 48.2 W at 60 G met; 62.8 W at 80 G not met |
| R4 | Not verifiable at TRL 3 | Settling ratio 36 or more for 20 µm flakes; bed behaviour needs testing |
| R14 | Not verifiable at TRL 3 | No wear data |
| R11 | Met (paper) | 77.3 kg in six loads, heaviest 18.1 kg; assembly time not verified |
| R12 | Met (paper) | Brake stop 0.6 s; motor capped; pedal-case burst factor 17 at 1,200 rpm with display; containment not verified |
| R1, R3, R7, R8, R10, R13 | Met (paper or design review) | Unchanged from v0.1 |

Summary: one not met, three at risk, two not verifiable, eight met on paper (was three not met and six met).

### Still awaiting Amish (no recommendation was made)

1. Cost-down options to close the $5 gap on R9: quarter-turn belt instead of the bevel gearbox (about $25), non-fluidized variant (about $45), table later (about $70 deferred). **Decided by Amish, 2026-09-26: budget set to $455 to cover the priced BOM, which closes the gap; see "Session 2026-09-26: budget approved".**
2. The first co-design partner (item 8b).
3. Head for the fluidization supply: a 1.7 m post or a small pump (item 11b).
4. Water pumping from the settling pond at pedal-only sites (item 12).
5. R2 and R5 margins: raise the design feed to about 210 kg/h, or restate R2 as 200 kg/h of feed time (item 13).

### Cross-repo actions (not changed in other repos)

- **MotionCore** (item 14 decided): raise with MotionCore (a) the reference hub motor's no-load speed, assumed 250 rpm at full pack voltage, which sets GravitySort's 1.2:1 step-up; (b) mounting a sprocket on the hub motor's disc mount for a stationary chain drive; (c) a speed-limit setting that maps to 900 rpm at the GravitySort spindle, since MotionCore sets its limit in wheel-speed terms; (d) use of a MotionCore brake input for the GravitySort lid switch.

### TRL 4

TRL 4 remains on hold by Amish's instruction. No build, test, purchasing, PCB or firmware work was done. The checks these decisions point at (bearing alignment on a 25 mm frame, spin-up with the tub and lid as containment, brake stop time) are TRL 4 work and are listed for later only. `trl: 3`, `trl_target: 3`.

## Session 2026-09-25: TRL 3

### What was done

- `docs/decisions/0001-trl2-review-decisions.md` (GVS-DDR-001 v0.1): TRL 2 items 2 to 7 and the partner screening criterion (item 8a) adopted as recommended for TRL 3 under Amish's 2026-09-25 instruction, open for his review; the budget, the partner itself and six new TRL 3 items listed as open.
- `docs/04-calcs/01-sizing.md` (GVS-CAL-001 v0.1) with `docs/04-calcs/sizing.py` and `results.csv`: speed and G, throughput with flush stops, water, settling in the bowl, fluidization jacket pressure and supply, power, mass balance, table drive, rotor inertia, burst, spindle, coast-down and brake, transport mass, cost and the gold balance. The script reads `cad/src/model.py` and `bom/bom.csv` and prints every quoted number.
- `cad/src/model.py`: parametric build123d model (frame, hopper, bowl with liner, shell and riffle rings, rotating jacket and rotary union, spindle with bearing units, brake disc and caliper, tub, lid, pedal station, jackshaft and gearbox, belts, guards, MotionCore module and hub motor, tank, table deck, stand and head, tray, speed display). Exports `cad/step/` and `cad/stl/` `gravitysort-assembly`, `gravitysort-bowl` and `gravitysort-table-deck`.
- `cad/src/sheets.py` and `cad/drawings/GVS-DWG-001.svg`, `.pdf`, `.png`: general arrangement, Rev P1, "CONCEPT, NOT FOR FABRICATION" and "PRELIMINARY, NOT FOR FABRICATION" (the concept sheet keeps GVS-DWG-010).
- `bom/bom.csv`: 19 lines, all priced with suppliers or supplier types; new items 18 (brake and lid interlock) and 19 (speed display); `bom/bom-notes.md` totals against $350 and $450.
- `cad/src/concept_media.py` now builds from the model; every image in `media/` regenerated and checked by eye; temporary `media/_views*` folders deleted.
- Docs updated to v0.3 with revision entries dated 2026-09-25: GVS-PRB-001, GVS-PRC-001, GVS-REQ-001. `project.yaml`: `trl: 3`, `trl_target: 3`, evidence listed; pitch and problem unchanged (no rewording was recommended). `README.md`: TRL 3, concept numbers from GVS-CAL-001, links to the drawing, sizing note and DDR, brake in the components and safety text.

### Requirements (GVS-CAL-001)

Six of fourteen met on paper; three not met; three at risk; two not verifiable at TRL 3.

| ID | Status | Value |
| --- | --- | --- |
| R9 | **Not met** | $465 against $350, and against the $450 recommended at TRL 2 (awaiting Amish) |
| R11 | **Not met** | 88.3 kg in six loads against 80 kg; every load under 30 kg (heaviest 25.8 kg) |
| R12 | **Not met as written** | Gearing cannot cap the pedal drive (900 rpm at a 75 rpm cadence); guards, lid interlock and brake (0.6 s stop, about 20 s coasting) are designed; motor capped by a 1.2:1 step-up and the MotionCore limit |
| R2 | At risk | 1.55 t per shift after three flush stops; 1.6 t needs 206 kg/h |
| R5 | At risk | Bowl pull 0.33 % is met; 5.3 kg per day needs 53:1 on the table, likely two passes |
| R6 | At risk | 48.2 W at 60 G is met; 62.8 W at 80 G is not; union seal drag assumed |
| R4 | Not verifiable at TRL 3 | Settling check passes (ratio 36 or more for 20 µm flakes); bed behaviour needs testing |
| R14 | Not verifiable at TRL 3 | No wear data |
| R1, R10 | Met (design review) | No mercury; no lathe (set-screw inserts, taper bush, printed mold) |
| R3, R7, R8, R13 | Met (paper) | 40 to 81 G over 600 to 850 rpm with a speed display; motor margin 5.2 times; 1.19 m3/h; toolless clamps |

Other key numbers: 165 J stored at 730 rpm (447 J at 1,200 rpm); burst safety factors at 1,200 rpm of 17 (jacket), 30 (shell) and 51 (ring lips); spindle first critical speed about 4,820 rpm; about 89 fluidization holes of 1.0 mm; 3.7 kPa at the rotary union with a 3/4 in hose; 0.55 kWh per shift on the motor.

TRL 2 numbers corrected: pedal power 45 to 48.2 W; stored energy 150 to 165 J; mass 75 to 88 kg; cost $437 to $465; motor energy 0.5 to 0.55 kWh; MotionCore $325 to $335; 1.6 to 1.55 t per shift.

### Decisions recorded (GVS-DDR-001)

Adopted as recommended for TRL 3 under Amish's 2026-09-25 instruction, open for his review: two stages (item 2); fluidized bowl with rotary union, non-fluidized variant documented (3); cast PU liner in a printed mold (4); pedal baseline with the MotionCore option and one time-shared drive (5); battery left to the user (6); direct smelting with borax as the downstream step (7); partner screening criterion (8a). The budget recommendation ($450) was not applied; `budget_usd` stays at $350.

### Still awaiting Amish

1. **Budget (item 1).** Recommended $450 at TRL 2; the BOM is now $465, over both. Cost-down options: quarter-turn belt instead of the bevel gearbox (about $25), non-fluidized variant (about $45), table later (about $72 deferred).
2. **First co-design partner (item 8b).** Not named.
3. **R12 pedal speed cap (item 9).** Recommendation: reword R12 for the pedal case to rely on the structural margin at 1,200 rpm plus the speed display; alternative is a slip clutch.
4. **R11 mass (item 10).** Recommendation: 25 x 25 x 1.5 mm frame tube (about 7.7 kg less) and a lighter table stand, then re-estimate; alternative is relaxing R11 to 90 kg.
5. **Fluidization supply (item 11).** 3/4 in hose (in the BOM), graded holes, and a 1.7 m post or a small pump for an even 10 kPa at every ring.
6. **Water pumping without power (item 12).** No recommendation yet.
7. **R2 and R5 margins (item 13).** Raise the design feed to about 210 kg/h or restate R2.
8. **Engineering proposals (item 14).** Disc brake with parking latch and lid pin; bicycle computer display; 1.2:1 motor step-up; MotionCore lid switch on a brake input.

### Cross-repo notes (not changed in other repos)

- **MotionCore:** consistent with MTC-DDR-001 and MTC-CAL-001: $265 kit plus $70 reference motor ($335, excluded from the GravitySort total), 20 to 58 V packs, stop category 0 (GravitySort therefore keeps its own mechanical brake), brake inputs used for the lid switch, speed sensor on the spindle. Two assumptions MotionCore does not state: the reference hub motor's no-load speed (assumed 250 rpm at full pack voltage) and mounting a sprocket on its disc mount for a stationary chain drive. The MotionCore speed limit is set in wheel-speed terms, so a GravitySort setting that maps to 900 rpm at the spindle is needed. No conflict found; these are questions for MotionCore, not changes.
- No other shared component (FieldNode, CellGuard, ThermaCart, TwinKit, CalRig) is used. SwapCell is not named (item 6).

### Safety concerns

- The bowl coasts for about 20 s after the drive stops; the brake and lid interlock are paper designs, and the lid pin must not be removable in normal use.
- A rider can reach about 1,200 rpm (447 J). Burst margins are large on paper but assume sound lamination and a bonded liner; containment of a 61 J liner fragment by the 6 mm HDPE tub and 10 mm lid is not verified.
- Mercury cross-contamination, arsenic and lead in concentrates, drowning risk at settling ponds and smelting heat are unchanged from TRL 2.
- The motor option brings a lithium pack to a wet, dusty site; MotionCore's stop does not brake.
- Concentrate theft and operator security remain a social risk for the partner.

### Other notes

- No TRL 4 material exists in the repo: no test plans or reports, build procedures, cut lists or purchasing lists. `build-log/README.md` is the scaffold stub and was not touched.
- Citations: the TRL 2 note lists no unchecked citations, so none were fetched; WebSearch was not used.
- The kit's cutaway cuts at the mean Y of the parts, which passes through the bowl axis; the model is not shifted. The water tank, water line, guards and speed display are left out of the section.
- build123d gives a shape only one parent compound, so `assemblies()` copies the parts for the bowl and deck sub-assemblies; without the copies the bowl and deck dropped out of the assembly STEP and the drawing views.
- `render.py --check` and `render.py` pass; PDFs are in `docs/pdf/`.

### Recommended next step

Review GVS-DDR-001, in particular the budget (item 1), R12 (item 9) and R11 (item 10), and decide how water is pumped at pedal-only sites (item 12). TRL 4 is on hold by Amish's instruction. For reference only, TRL 4 would need: a bench build of the bowl, jacket, spindle and brake; a lab test report (TST, `environment: lab`) covering liner casting and bond, spin-up with the lid and tub as containment, coast-down and brake stop time, union seal drag and pedal power, fluidization flow per ring, and recovery with tungsten or magnetite tracers; and build-log entries. None of this has been started.

## Session 2026-09-25: /populate to a strong TRL 2

### What was done

- `docs/01-problem.md` (GVS-PRB-001 v0.2): the problem with cited figures, users and operating environment, constraints, out of scope, prior work with sources (commercial centrifuges and tables, the CICAN project in Colombia, the Benguet borax method, planetGOLD), open questions; co-design checklist kept.
- `docs/03-requirements.md` (GVS-REQ-001 v0.2): 14 measurable requirements (R1 to R14) with targets, planned verification and concept status.
- `docs/02-concept.md` (GVS-PRC-001 v0.2): how it works, drive train, components table numbered to the BOM and exploded view, first-order numbers with assumptions, gold balance, key design choices, safety, open questions.
- `cad/src/concept_media.py`: massing model (frame, hopper and screen, bowl with riffle rings, fluidization jacket and rotary union, spindle, splash tub and launder, lid guard, pedal station, jackshaft and gearbox, belts, guards, MotionCore module and motor, water tank, shaking table deck, table stand and head motion, concentrate tray) with the 1.75 m scale figure.
- `media/`: hero, blueprint sheet (PNG, PDF, SVG), cutaway, exploded view with BOM callouts, gold balance flow diagram (estimates marked), `model.glb` and `viewer.html`.
- `bom/bom.csv`: 17 lines with indicative prices, numbered to match the exploded view; `bom/bom-notes.md` with group totals.
- `README.md`: hero image and links line; Concept rationale, Burning platform, Where it could be used (6 industries, 5 countries or regions), What sparked the idea, Problem, Concept, Key components and Safety expanded with cited sources.
- `docs/pdf/`: branded PDFs of the three controlled documents.
- `project.yaml`: unchanged. The pitch and problem still match the sources found.

### Key results (estimates, to be checked at TRL 3)

| Quantity | Estimate | Requirement |
| --- | --- | --- |
| Bowl speed and force | 730 rpm for 60 G at 100 mm; 600 to 850 rpm for 40 to 80 G | R3 met on paper |
| Throughput | 200 kg/h, 1.6 t per 8 h day | R2 met on paper |
| Input power | about 45 W (27 W slurry and water, 10 W losses, 85 % drivetrain) | R6 met on paper, at risk; R7 met |
| Motor energy | about 0.5 kWh per day | Information |
| Water | about 1.2 m3/h (0.47 slurry, 0.72 fluidization) | R8 met on paper |
| Mass pull | about 0.3 % to the bowl; about 5 kg per day to about 100 g on the table | R5 met on paper |
| Overall gold recovery | about 60 % on free-gold ore (reference 5 g/t: 4.8 of 8.0 g per day) | R4 not verifiable before testing, at risk |
| Size and mass | about 2.72 x 0.78 x 1.65 m; about 75 kg in four loads | R11 met on paper |
| Parts cost | about $437, MotionCore and battery excluded | **R9 not met**, about 25 % over $350 |

Requirements not met or at risk: **R9** (budget) is not met. **R4** (recovery) cannot be verified on paper and is the main technical risk. **R6** (pedal power) depends on the rotary union seal and bearing drag, which are guesses. **R12** is only partly met because the bowl brake is not yet designed. **R14** (liner life) is not verifiable at TRL 2.

### Proposed, awaiting Amish

1. **Budget.** Options: (a) raise `budget_usd` to $450; (b) keep $350 and phase the build, centrifuge stage and pedal drive first (items 1 to 11, 13 and 17, about $365) with the table later (about $72); (c) keep $350 and drop fluidization (saves about $45, lower fine-gold recovery). Recommendation: (a), because the table is what makes mercury-free smelting practical. `project.yaml` is unchanged at $350.
2. **Two stages (centrifuge then table)** over a centrifuge alone or a table alone. Recommendation: two stages.
3. **Fluidized bowl with a rotary union** over a non-fluidized bowl. Recommendation: fluidized, with the non-fluidized bowl kept as a documented low-cost variant.
4. **Bowl liner:** (a) cast polyurethane in a 3D-printed mold; (b) turned HDPE (needs a lathe); (c) printed bowl (low wear life). Recommendation: (a).
5. **Drive:** pedal crank as baseline with MotionCore 250 W as the option, one drive time-shared between bowl and table. Recommendation: as proposed.
6. **Reference battery for the motor option:** (a) leave it to the user (any 24 to 48 V pack MotionCore accepts); (b) name the SwapCell pack, whose about 468 Wh matches about one day of motor running. Recommendation: (a) for now; revisit after co-design shows whether users want the motor.
7. **Final step:** document direct smelting with borax as the recommended downstream method, outside the scope of this hardware. Recommendation: yes.
8. **First co-design partner:** options include a planetGOLD country programme, a university mining department in Ghana, Peru or Colombia, or a cooperative using the Benguet method in the Philippines. Recommendation: a partner in a country with a mercury ban already in force (Colombia) or a Minamata action plan with a planetGOLD programme.

### Dependencies

- **MotionCore:** GravitySort uses the MotionCore reference drive (250 W, 24 to 48 V, hardwired e-stop and independent speed limit) as its motor option, consistent with the MotionCore README. The MotionCore cost (about $325) is not in the GravitySort total.

### Safety concerns

- Rotating bowl at up to 850 rpm with about 150 J of stored energy, plus belts, chains and a moving table head: guards and a lid guard are in the model, but there is no interlock and no brake yet. A bowl brake and a guard interlock should be designed at TRL 3.
- Liner failure at speed could throw fragments; a burst check of the liner and shell belongs in the TRL 3 calculation note.
- Mercury cross-contamination: the machine must never be used with mercury or on untested legacy tailings. This must be stated in any user guide.
- Arsenic and lead minerals in concentrates; drowning risk at settling ponds; smelting heat (outside the machine).
- The motor option brings lithium cells to a wet, dusty site; MotionCore's safety section applies.
- Concentrate theft and the personal security of operators: the lockable tray and container help, but this is a social risk the partner must address.

### Suggestions (not in scope for this session)

- A simple recovery test protocol with tungsten or magnetite tracers would be the first TRL 4 activity, after Amish approves.

### Recommended next step

Review this note and the media. If approved, run `/advance-trl3` to size the bowl, fluidization flow and drive by calculation, check the liner and bowl for burst at 1.2 times maximum speed, design the bowl brake and guard interlock, settle the gearbox source, price the BOM with named suppliers, and produce the parametric model and drawing sheet.

## Session 2026-09-26: product appearance model and photoreal renders

Amish chose this repo for the first batch of product renders on 2026-09-26.
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

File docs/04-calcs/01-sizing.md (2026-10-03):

---
doc_id: GVS-CAL-001
title: GravitySort sizing calculations
project: GravitySort
doc_type: Calculation note
version: "0.8"
status: Draft
date: '2026-10-02'
author: Amish Chadha
license: CERN-OHL-S-2.0
revisions:
- version: "0.1"
  date: '2026-09-25'
  author: Amish Chadha
  change: First TRL 3 sizing note (speed and G, throughput, water, settling, fluidization supply, power, mass balance, table drive, rotor safety and brake, mass, cost, gold balance)
- version: "0.2"
  date: '2026-09-25'
  author: Amish Chadha
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

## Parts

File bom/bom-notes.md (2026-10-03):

# BOM notes

Prices are indicative TRL 3 estimates with a supplier or supplier type on every line; none is a quotation. Row numbers match the exploded view (`media/exploded.png`) and Table 1 of the design precis. Items 18 and 19 are new at TRL 3; item 23 (the flush container) was added on 2026-10-02. Items 1 and 15 use 25 x 25 x 1.5 mm tube under GVS-DDR-002 (Amish's decision of 2026-09-25). On 2026-10-01 the lines were updated for the constructable design (GVS-DDR-003): every part the build plan (GVS-BLD-001) needs is now in a line, and item 20 (the motor cradle) is new. The total is checked by `docs/04-calcs/sizing.py` (GVS-CAL-001 section 12).

**The MotionCore kit and reference motor (item 12) are not included in the GravitySort total.** They are shared lab components with their own budget: $265 for the kit plus $70 for the reference hub motor, $335 in all (MTC-CAL-001). The pedal drive is the baseline. The battery for the motor option is the user's choice and is not included either. The motor cradle (item 20) is specific to GravitySort and is included.

| Group | Items | Cost |
| --- | --- | --- |
| Centrifuge stage and frame | 1 to 7 | $243 |
| Pedal drive and transmission | 8 to 11 | $120 |
| Water supply | 13 | $41 |
| Shaking table | 14 to 16 | $100 |
| Table bump stop | 21 and 22 | $11 |
| Hardware | 17 | $22 |
| Bowl brake, lid interlock and speed display | 18 and 19 | $28 |
| Motor cradle (motor option) | 20 | $8 |
| Flush container with padlock hasp | 23 | $7 |
| **GravitySort total, MotionCore excluded** | 1 to 11, 13 to 23 | **$580** |
| Motor option (MotionCore kit and reference motor, battery excluded) | 12 | $335 |

Value-engineering target: USD 455. Estimated cost of the constructable design: USD 580 (USD 125 over the target). The target, `budget_usd` in `project.yaml`, is a hypothetical control target that keeps the design on a value-engineering lens, not a spending limit (Amish, 2026-10-01). The concept BOM was $455; making every part buildable added $103, mostly in the table stand and head (+$24), the frame (+$11), the tub fittings (+$14) and the bowl hub and fixings (+$10). Lines 21 and 22 (the table bump stop decided by Amish on 2026-10-01, GVS-DDR-003 A2) add $11. The decisions of 2026-10-02 (GVS-DEC-001) add $11 more: the 1.7 m braced tank post adds about 1.9 m of tube and its welding to line 1 ($43 to $47), and line 23 is the flush container with its padlock hasp ($7). The main cost drivers and the savings worth trying are listed in the Value engineering section of the design decisions register (`docs/06-design-decisions.md`).

Water reaches the header tank by gravity from upstream as the site rule for the first field trial; where that is impossible, a bought treadle or hand pump, or a small 12 V pump at sites with the MotionCore battery, is used (Amish, 2026-10-02, GVS-DEC-001). No pump is in this BOM. The header tank post rises to 1.7 m with two braces (line 1), and the flush container carries a padlock hasp like the concentrate box (line 23); both decided 2026-10-02. Padlocks are left to the partner, two per hasp if the two-person rule is adopted.

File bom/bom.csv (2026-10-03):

item | qty | spec | supplier | unit_cost_usd | make_buy | notes
1 Base frame | 1 | 25 x 25 x 1.5 mm mild steel square tube, 16.4 m (model, GVS-DWG-101), welded; 900 x 600 x 700 mm with lower rails, gearbox, spindle and tub members, drop posts, end post, a 995 mm tank post (cradle at 1.7 m) and two 717 mm braces to the top side rails; two 150 x 130 x 6 mm bearing plates; 250 x 250 x 5 mm tank cradle with gussets; primer and paint | Local steel stockist and welder | 47.00 | make | Indicative: about 16.5 m of tube at about $1.80/m, about 5 kg of plate, welding consumables and paint; constructable layout per GVS-DDR-003 (was 11.75 m, $32); 1.7 m braced tank post per GVS-DEC-001 2026-10-02 adds 1.9 m of tube and its welding, $4 (was $43)
2 Feed hopper with screen | 1 | Sheet steel cone 140 to 340 mm, 220 mm tall, 2 mm punched stainless screen 360 mm in a flat bar rim, 44 x 6 mm feed pipe ending 15 mm above the lid; support post, arm and 6 mm ring on the front top rail (GVS-DWG-109, 110) | Local metal shop | 24.00 | make | Indicative; support added per GVS-DDR-003 (was $18)
3 Centrifugal bowl with riffle rings | 1 | 220 mm lip, 130 mm base, 180 mm deep (liner surface); four riffle rings 6 mm thick, 12 mm deep; about 89 fluidization holes of 1.0 mm; 8 mm cast polyurethane liner Shore 80 to 90A cast in the shell on a printed core in six segments; four cast-in M6 stainless nuts; 4 mm hand-laid GFRP shell on a printed plug (GVS-DWG-104, 105) | Chemical or resin supplier (PU and GFRP); local 3D printing service for the mold | 46.00 | make | Indicative: PU about 1.2 kg and GFRP about 1 kg of glass and resin plus about 1 kg of plug and core filament (was $45)
4 Fluidization jacket and rotary union | 1 | 4 mm GFRP jacket, 12 mm gap, with a bonded closing ring; 25 mm bore shaft flange hub, 80 mm flange, pinned; four M6 bolts with 12 mm spacer bushes; 1/2 in single-passage water rotary union at the spindle foot; 8 to 15 L/min (GVS-DWG-106) | Industrial or hydraulic fittings supplier (union); resin supplier (jacket) | 55.00 | buy | Indicative; union seal drag assumed 0.10 N m (GVS-CAL-001) until a datasheet is chosen; hub, bolts and spacers added per GVS-DDR-003 (was $45)
5 Spindle bearings and pulley | 1 | 25 x 2 mm stainless 316 tube 372 mm (water passes up the bore) with a 1/2 in BSP stainless nipple welded in its foot, two UCF205 flanged insert bearing units with set screws, 100 mm A-section pulley with taper bush (GVS-DWG-103) | Bearing and power transmission shop | 35.00 | buy | Indicative price; no lathe work: set-screw inserts, taper bush and a welded nipple (GVS-DDR-003)
6 Splash tub and tailings launder | 1 | Cut HDPE drum about 430 mm diameter, 6 mm wall, 320 mm tall; 63 mm standpipe through a rubber pipe grommet in the floor; 75 mm tailings pipe through a rubber pipe grommet in the back wall, hose on to the settling pond (GVS-DWG-107) | Local market (used drum) | 26.00 | make | Indicative; standpipe, grommets and pipe added per GVS-DDR-003 (was $12)
7 Bowl lid guard | 1 | 10 mm HDPE disc 446 mm diameter, 60 mm feed hole, two toolless over-centre clamps on the tub wall, one with a hole for the interlock pin (GVS-DWG-108) | Plastics supplier; hardware store (clamps) | 10.00 | make | Indicative price
8 Pedal station | 1 | Used bicycle bottom bracket shell, axle, crank, 48T chainring, pedals, seat and seat post; welded outrigger in 25 x 25 x 1.5 mm tube (2.1 m) with a 32 x 2 mm round seat tube and two 6 mm end plates, bolted to the frame end (GVS-DWG-102) | Bicycle repair shop (used parts) | 28.00 | buy | Indicative; outrigger detailed per GVS-DDR-003 (was $25)
9 Jackshaft gearbox chains and pulleys | 1 | 20 mm shaft on two bearings, 12T freewheel, 1:1 right-angle bevel gearbox, 300 mm drive pulley, motor sprocket (ratio set per motor, GVS-CAL-001), 140 mm table take-off pulley, two chains | Power transmission shop; used agricultural or garden machine for the gearbox | 60.00 | buy | Indicative; gearbox source open; a quarter-turn belt could replace the gearbox (cost-down option in docs/REVIEW.md)
10 Drive belts | 2 | A-section V-belts: bowl belt as a link V-belt (fixed pulley centres, length set by its links); table belt slack until the tensioner is set | Power transmission shop | 5.00 | buy | Indicative price
11 Belt and chain guards | 1 | 1.2 mm perforated steel sheet: bowl belt guard on four hangers, pedal chain case, table belt guard (GVS-DWG-111, 112, 119) | Local metal shop | 22.00 | make | Indicative; table belt guard added per GVS-DDR-003 (safety note of 2026-09-26; was $15)
12 MotionCore kit and reference hub motor | 1 | MotionCore kit (module, e-stop, brake inputs, speed sensor) and reference 250 W geared hub motor with a sprocket on its disc mount; 20 to 58 V pack | MotionCore project | 0.00 | make | NOT INCLUDED in the GravitySort total: $265 kit plus $70 motor = $335 per MTC-CAL-001; battery not included
13 Water header tank valve and flow meter | 1 | 60 L HDPE drum on the frame's tank cradle with a ratchet strap, 3/4 in ball valve, 2 to 20 L/min rotameter on a bracket on the back top rail, 3/4 in hose down the back to the rotary union; tee, valve and hose to the table wash pipe | Local market and irrigation supplier | 41.00 | buy | Indicative; rotameter bracket and wash water branch added per GVS-DDR-003 (was $35)
14 Shaking table deck | 1 | 1000 x 450 mm, 18 mm marine plywood faced with 3 mm HDPE, nine tapered riffles, feed box, pitman cheeks; 40 mm PVC wash water pipe drilled along the back edge (GVS-DWG-114) | Timber yard and plastics supplier | 34.00 | make | Indicative; wash pipe added per GVS-DDR-003 (was $30)
15 Table stand and head motion | 1 | Table base in 25 x 25 x 1.5 mm tube (2.4 m); four 18 mm marine plywood flexure legs with eight 40 x 40 x 4 mm angle cleats; 6 mm head plate and shelf bolted to the frame end; two 20 mm pillow blocks, 20 mm head shaft, eccentric disc (15 mm stroke) and 125 mm pulley; pitman arm with a bronze bush; belt tensioner (60 mm idler on an arm with a latch) (GVS-DWG-115, 116, 117, 119) | Local metal shop | 52.00 | make | Indicative; head bolted to the frame instead of a separate post, tensioner detailed per GVS-DDR-003 (was $28)
16 Concentrate launder and lockable tray | 1 | Sheet steel tailings launder under the deck's front edge on two legs; lockable concentrate box under the deck's far end on four legs, hinged lid and padlock hasp (GVS-DWG-118) | Local metal shop | 14.00 | make | Indicative; box moved under the gold end of the riffles per GVS-DDR-003 (was $12)
17 Hardware hoses and sealant | 1 | Fasteners (M6, M8, M10 bolts and nylock nuts, about 60), hose clamps, ratchet strap, sealant, O-ring, paint | Hardware store | 22.00 | buy | Indicative price; more fixings in the constructable design (was $15); partly modelled
18 Bowl brake and lid interlock | 1 | 160 mm bicycle disc rotor on a 6 mm flange welded to a 25 mm bore shaft collar on the spindle, mechanical disc caliper on a 6 mm L bracket on the spindle member, lever with parking latch on the end top rail and cable; lid interlock pin on the same cable (GVS-DWG-113) | Bicycle repair shop; local metal shop (bracket and flange) | 18.00 | buy | Indicative price
19 Bowl speed display | 1 | Wired bicycle computer on the end top rail facing the rider, sensor under the belt guard, magnet on the spindle pulley, wheel size set to 1667 mm so the display reads bowl rpm divided by 10 | Bicycle shop | 10.00 | buy | Indicative price
20 Motor cradle and motor chain guard (motor option) | 1 | 6 mm base plate 130 x 117 mm bolted on the back lower rail, two 6 mm dropouts with open axle slots; sheet chain guard on two spacers (GVS-DWG-120) | Local metal shop | 8.00 | make | Only with the MotionCore option; counted in the GravitySort total because it is specific to this machine (GVS-DDR-003)
21 Table bump stop bracket and striker | 1 | Stop bracket: 25 x 25 x 1.5 mm tube arm 244 long on a 40 x 66 x 6 mm foot plate (two M8 down through the frame's table-end top rail) with a 40 x 61 x 6 mm upright, 9 mm hole for the stud; striker: 6 mm steel angle 40 wide (40 and 70 mm legs) screwed under the deck's head end at its back edge; primer and paint (GVS-DWG-121) | Local metal shop | 6.00 | make | Indicative; asymmetric table stroke per GVS-DDR-003 A2 (accepted by Amish 2026-10-01)
22 Table bump stop buffer and fixings | 1 | Cylindrical rubber-metal buffer 40 mm diameter, 30 mm tall, natural rubber about 55 Shore A, M8 female thread, rated 600 N or more in compression; M8 stainless threaded rod 45 long; three M8 nuts (two lock the stud on the upright, one locks the buffer); two M8 bolts for the foot; two M6 bolts with large washers for the striker | Industrial rubber or hardware supplier | 5.00 | buy | Indicative price; buffer sized in GVS-CAL-001 section 9
23 Flush container with padlock hasp | 1 | 10 L HDPE pail with a push-on lid, about 250 mm across and 280 mm tall; steel hasp and staple about 36 x 100 mm, the staple riveted to the pail wall and the hasp strap riveted to the lid, each with four rivets and backing washers inside; padlocks supplied by the partner (two for the two-person rule) | Local market (pail); hardware store (hasp and rivets) | 7.00 | buy | Indicative: pail and lid about $4, hasp, staple and rivets about $3; concentrate security per GVS-DEC-001 (Amish, 2026-10-02); loose item, travels with load 6

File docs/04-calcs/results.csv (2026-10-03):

id | quantity | value | target | status
R1 | No mercury | no amalgamation step in the flowsheet | no mercury at any step | Met (design review)
R2 | Ore per 8 h shift | 200 kg/h; 1.55 t per shift with 3 flush stops | 200 kg/h of feed time, about 1.55 t per 8 h shift | Met (paper)
R3 | Bowl G at 100 mm over the speed range | 40 to 81 G (600 to 850 rpm); speed display item 19 | 40 to 80 G, speed shown | Met (paper)
R4 | Fine-gold recovery | settling ratio 36 or more for 20 um flakes; overall 60 % assumed | 80 % / 50 % in bowl; 60 % overall | Not verifiable at TRL 3 (at risk)
R5 | Concentrate for direct smelting | bowl pull 0.33 %; 5.3 kg/day needs 53:1 on the table | 0.5 % or less; 100 g or less | At risk (table ratio needs two passes)
R6 | Pedal power at full throughput | 48.2 W at 60 G; 62.8 W at 80 G | 60 W or less at 55 to 70 rpm | At risk (met at 60 G, not at 80 G)
R7 | Motor power margin | 5.2 x at 60 G (4.0 x at 80 G) | 3 x or more | Met (paper)
R8 | Water use at 200 kg/h | 1.19 m3/h | 1.5 m3/h or less | Met (paper)
R9 | Parts cost | $580 | value-engineering target $455 | Over the value-engineering target by $125
R10 | Local workshop build | welding, drill press, printed mold and segmented core; set-screw inserts, taper bush, welded nipple, no lathe | no lathe | Met (design review); casting route unproven
R11 | Transport mass | 99 kg total in 6 loads, heaviest 27 kg | 100 kg or less; loads 30 kg or less | Met (paper)
R12 | Guards, speed limit, stop time | brake stop 0.6 s (coast 20 s); motor capped by ratio and MotionCore; pedal: SF 16 at 1200 rpm, speed display | guarded; motor 900 rpm or less; pedal SF 10 or more at sprint speed with display; stop within 15 s | Met (paper); containment not verified
R13 | Quick, secure clean-up | toolless lid clamps; flush into lockable container; lockable tray | 5 min, no tools | Met (paper); time not verified
R14 | Liner life | no wear data for this PU on quartz | 500 h; replace in 30 min | Not verifiable at TRL 3

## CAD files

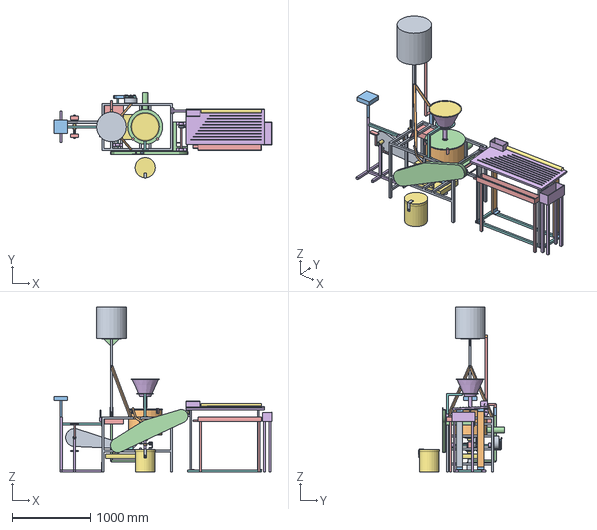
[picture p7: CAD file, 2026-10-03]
cad/step/gravitysort-assembly.step
2778.5 x 1100.0 x 2100.0 mm

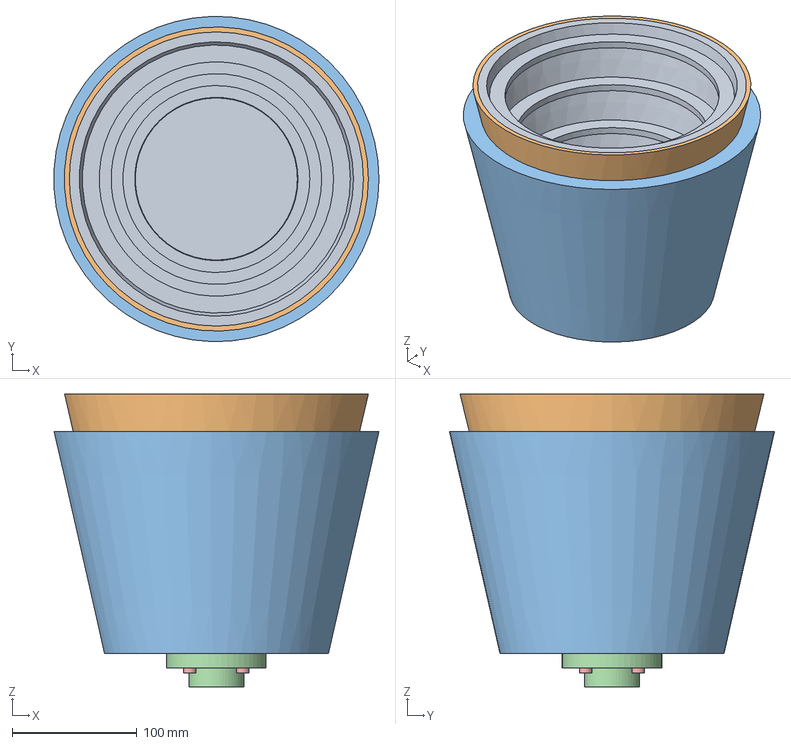
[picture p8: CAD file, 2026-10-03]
cad/step/gravitysort-bowl.step
260.8 x 260.9 x 235.0 mm

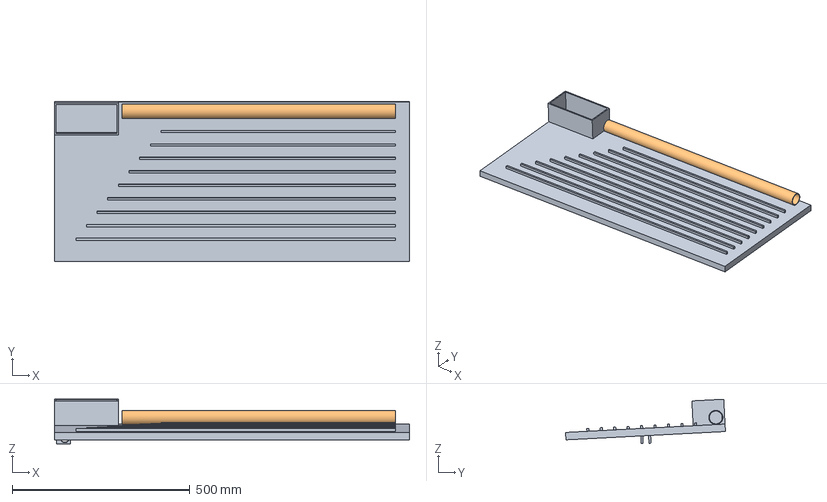
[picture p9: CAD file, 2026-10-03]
cad/step/gravitysort-table-deck.step
1000.0 x 450.5 x 125.4 mm

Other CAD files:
cad/stl/gravitysort-assembly.stl
cad/stl/gravitysort-bowl.stl
cad/stl/gravitysort-table-deck.stl

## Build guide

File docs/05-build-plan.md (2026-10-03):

---
doc_id: GVS-BLD-001
title: GravitySort prototype build plan
project: GravitySort
doc_type: Build plan
version: "0.4"
status: Draft
date: '2026-10-02'
author: Amish Chadha
license: CERN-OHL-S-2.0
revisions:
  - version: "0.1"
    date: '2026-10-01'
    author: Amish Chadha
    change: First build plan; design made constructable (GVS-DDR-003)
  - version: "0.2"
    date: '2026-10-01'
    author: Amish Chadha
    change: GVS-DDR-003 accepted by Amish
  - version: "0.3"
    date: '2026-10-01'
    author: Amish Chadha
    change: Table bump stop (GVS-DDR-003 A2) added to section 3.16 and step 16, with its making sketch (GVS-DWG-121) and joint close-up; pitman pin works in a slot; first checks and safety stops updated
  - version: "0.4"
    date: '2026-10-02'
    author: Amish Chadha
    change: Decisions of 2026-10-02 carried in. Tank post 1.7 m on the centre line with two braces (section 3.1, step 13, frame sketch GVS-DWG-101 Rev P2, frame cut picture, joint 8); flush container with a padlock hasp (section 3.21, Figure 38); overview and step pictures redrawn; mass, cost, first checks and safety stops updated
---

# GravitySort prototype build plan

**Plan, not yet built.** How to build the first proof-of-concept prototype, component by component. Building and testing to it is TRL 4 work. Decisions still to be made are kept in the design decisions register ([docs/06-design-decisions.md](06-design-decisions.md)), not here.

## 1. What you are building

Figure 1. Every component, pulled apart and numbered in build order

*Figure 1. Every component pulled apart and numbered in build order; 26, the motor, is an option; 27 is the loose flush container.*

The prototype is one GravitySort machine: a welded steel frame about 900 mm long, 600 mm wide and 700 mm tall that carries a spinning bowl inside a plastic tub, a pedal seat bolted to one end and a shaking table bolted to the other, with a water tank on a braced post, its cradle 1.7 m above the ground. Pedalling turns a jackshaft under the frame; a right-angle gearbox and a V-belt spin the bowl at about 730 rpm, and a second belt, engaged by a hand lever, drives the table at clean-up. Figure 1 shows the 27 groups of parts in the order you make or fit them; the last, the flush container, is a loose bought item. The work is sawing, drilling and MIG or stick welding square steel tube and plate; laying up glass fibre over 3D-printed plugs and casting polyurethane in the bowl; cutting a plastic drum and HDPE sheet; plywood work for the table; and fitting bought bicycle, bearing and belt-drive parts. The whole machine weighs about 99 kg in six loads of 28 kg or less. The parts cost about $580 from the bill of materials.

> **Safety:** GravitySort is rotating machinery. The bowl stores about 165 J at 730 rpm and coasts for about 20 s after the drive stops; belts, chains and pulleys can trap fingers, hair and clothing. Keep every guard on whenever the drive can turn, and keep the lid clamps shut and the brake parked whenever the bowl is not in use. Welding, grinding and cutting steel need a welding helmet, gloves, eye and hearing protection and a fire-safe area. Epoxy, glass fibre and polyurethane casting need gloves, a respirator rated for organic vapour and good ventilation. Never use the machine with mercury.

## 2. What changed to make it buildable

The concept showed what GravitySort does; some of its parts could not be made, fixed or assembled as drawn. Each change below keeps what the machine does, and all of them are recorded in decision record GVS-DDR-003, accepted by Amish on 2026-10-01; the water row also carries Amish's decisions of 2026-10-02 on the tank post.

*Table 1. Changes from the concept.*

| Component | The concept had | The buildable design has | Why |
| --- | --- | --- | --- |
| Frame | Cross members at heights where no rail met them, and two members that the spindle and the gearbox shaft passed straight through | Lower side rails carrying two pairs of members, one pair each side of each shaft; the tub members hung on four drop posts; end post and end members (Figure 3) | Every tube now welds to two others, and the shafts pass between members |
| Spindle bearings | Flanged bearings with nothing to bolt to | Two 6 mm plates welded under the member pairs; each bearing hangs under its plate (Figure 7) | A bearing needs a flat face for its four bolts |
| Spindle | A solid 25 mm shaft, though water must pass up it to the jacket | A 25 x 2 mm stainless tube with a nipple welded in its foot for the rotary union (Figure 6) | Water reaches the jacket without drilling a long hole |
| Bowl and jacket | No fixing to the spindle; the jacket open at the top | A flange hub pinned to the spindle, four bolts with spacers into nuts cast in the liner; a bonded ring closes the jacket (Figure 13) | The water can only leave through the ring holes |
| Liner core | A one-piece core that could not come out past the riffle rings | A printed core in six segments round a key (Figure 11) | The rings are undercuts |
| Tub | A centre hole over the upper bearing; a launder box through an uncut wall | A standpipe in a rubber grommet; a tailings pipe through a rubber grommet in the back wall (Figures 15 and 16) | Spilt slurry cannot reach the bearing; no plastic welding |
| Feed pipe | Ran down through the lid into the bowl, so the lid could not come off | Stops 15 mm above the lid (Figure 21) | The lid lifts straight off to flush the bowl |
| Pedal drive | The chain crossed a frame member; the outrigger arms ended in the air | Bottom bracket 100 mm above the jackshaft; outrigger bolted to the frame end by two plates (Figure 5) | The chain clears the frame; the outrigger lifts off for transport |
| Table drive | The take-off pulley ran into the members; the table belt looped round a frame rail | The jackshaft runs out in front of the frame; the table belt runs outside the frame | Nothing passes between the belt's two runs |
| Table | Solid legs; head on a single post; no clutch; concentrate tray where the tailings fall | Plywood flexure legs; head bolted to the frame end; a latched belt tensioner; tailings launder at the front and concentrate box at the far end (Figures 25 to 35) | Each product goes where the table delivers it |
| Table stroke | A plain eccentric and pitman, which shake the deck in a nearly even to-and-fro that does not move gold along the table | An adjustable rubber stop on a bracket on the frame's table end; the deck strikes it at the end of each forward stroke, and the pitman pin works in a short slot so the deck can stop while the pin runs on (Figures 29 and 30) | Gold walks toward the concentrate box only if the deck turns back sharply at its far end (GVS-DDR-003, A2, accepted by Amish on 2026-10-01) |
| Motor option | The motor enclosed its own chain | A bolt-on cradle behind the frame (Figure 37) | The chain clears the motor |
| Water | The hose ran through the drive pulley; the tank post was not drawn; the tank stood too low to give the bowl its water pressure | A tank post on the centre line with its cradle 1.7 m up, braced to the front and back top rails; the hose runs down outside the back of the frame | Clear path; the height gives the water pressure the bowl needs without a pump, and the braces and the central post stop a full tank tipping the machine |

## 3. Making the components

Make and check each component before the assembly step that needs it. Sizes are in millimetres. "Front" is the side the hopper post stands on; "left" and "right" are as seen standing in front, so the pedal end is on the left and the table on the right. Heights are from the ground with the frame standing on level ground. Workshop tolerance is 1 mm unless a step says otherwise; drawings do not carry tolerances before TRL 4.

### 3.1 Base frame

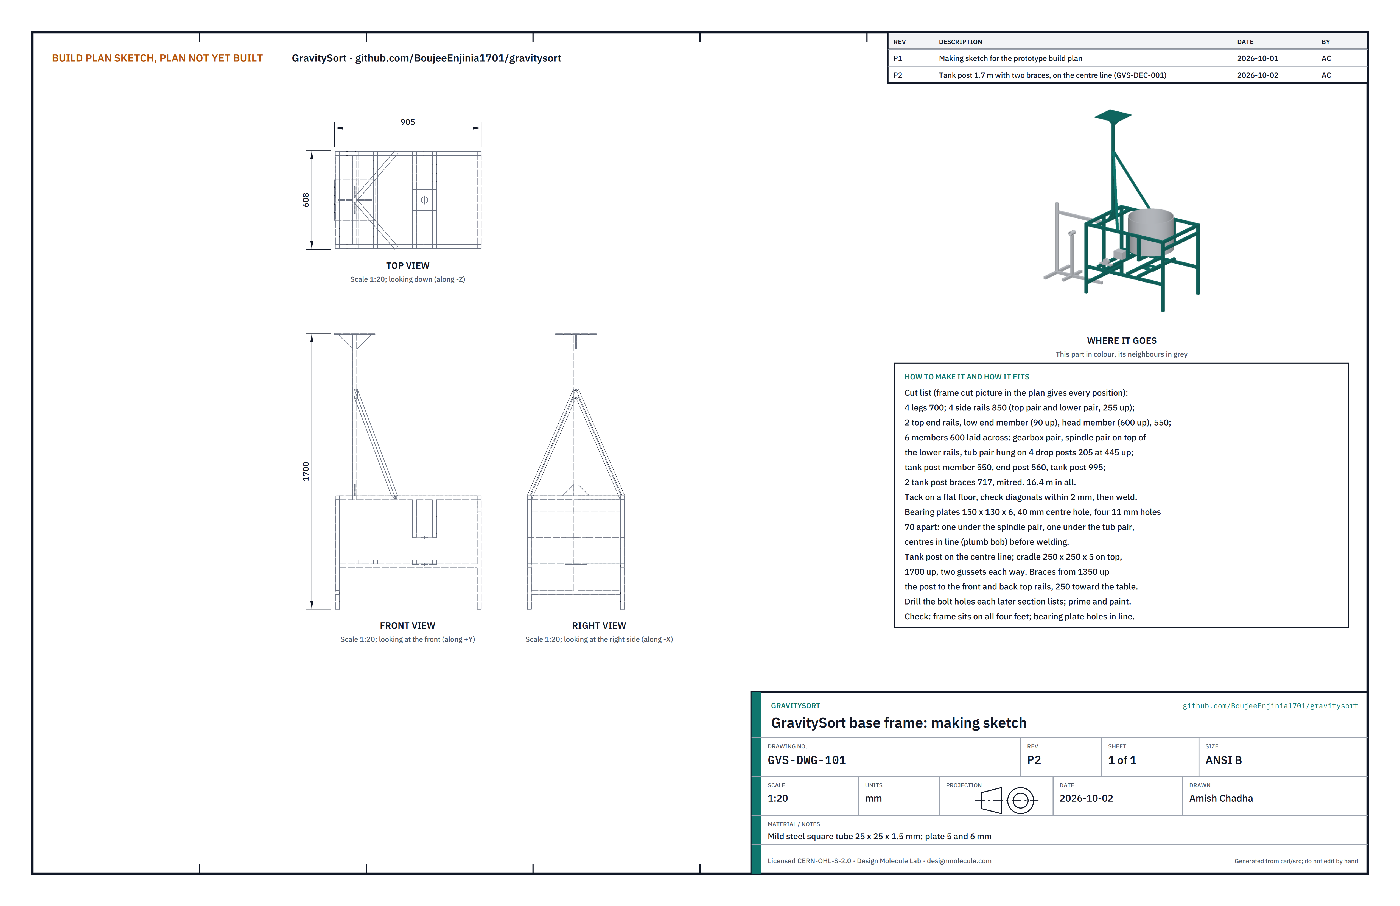
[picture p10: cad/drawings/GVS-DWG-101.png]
Figure 2. Making sketch of the base frame


*Figure 2. Base frame making sketch (GVS-DWG-101).*

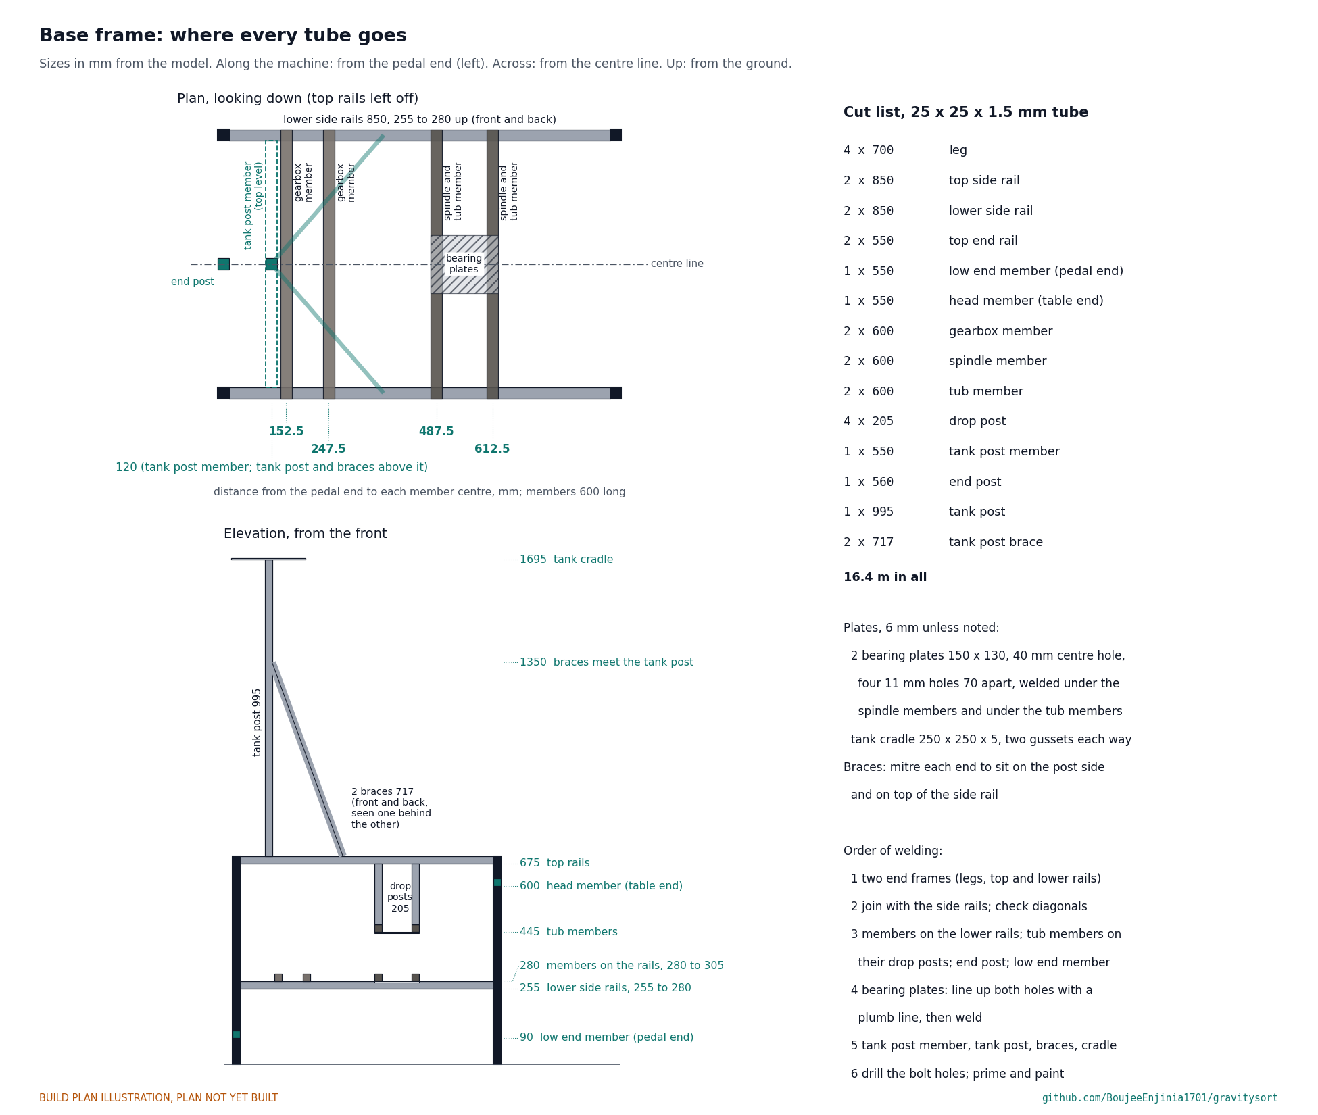
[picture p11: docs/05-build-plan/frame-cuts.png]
Figure 3. Where every tube of the frame goes


*Figure 3. Plan, elevation and cut list of the frame.*

**What it is and what it is made from.** The welded frame that carries everything else: the spindle and its bearings, the gearbox and jackshaft, the tub, the hopper and the water tank. Mild steel square tube 25 x 25 x 1.5 mm, 16.4 m in all; two bearing plates 150 x 130 x 6 mm; a tank cradle plate 250 x 250 x 5 mm with four gussets.

**How to make it.**

1. Cut the tubes to the cut list of Figure 3; square and deburr every end.
2. Build the two end frames flat on the floor: two legs 700 tall, a top end rail 550 long between them at the top, and, at the pedal end only, the low end member 550 long with its bottom 90 above the ground.
3. Stand the end frames up 900 apart (outside to outside) and join them with the four side rails, 850 long: two at the top and two with their bottom 255 above the ground. Tack, check that the diagonals of the top and of each side match within 2 mm, then weld.
4. Lay the four 600 mm members across the lower side rails: the two gearbox members with their centres 152.5 and 247.5 from the pedal end, and the two spindle members at 487.5 and 612.5. Weld.
5. Weld the two tub members, 600 long, 445 above the ground, each held up by two drop posts 205 long from the top side rails, directly above the spindle members.
6. Weld the end post (560) upright at the middle of the pedal end, from the low end member to the top end rail, and the head member (550) between the table-end legs with its bottom 600 above the ground.
7. Weld the tank post member (550) between the top side rails, 120 from the pedal end, and the tank post (995) upright on it, on the centre line. Weld the cradle plate on top, 1,700 above the ground, and a pair of gussets each way at both ends of the post. Cut the two braces (717 long on their centre line), mitre each end so it sits flat on the side of the post and on top of a top side rail, and weld them from the post, 1,350 above the ground, down to the front and the back top side rail, 370 from the pedal end.
8. Drill each bearing plate: a 40 mm centre hole and four 11 mm holes at the corners of a 70 mm square. Clamp one plate under the spindle members and one under the tub members, both centred on the bowl axis, 550 from the pedal end on the centre line. Hang a plumb line through both centre holes; when it passes through both centres, weld the plates.
9. Drill the bolt holes listed in the later sections (tub, hopper foot, outrigger plates, head plate, caliper bracket, belt guard hangers, tensioner bracket, motor cradle). Prime and paint.

**How it fits the parts next to it.** Everything else bolts to it; see each section.

**Check before moving on.** The frame stands on all four feet without rocking; a plumb line through the two bearing plate holes is within 1 mm of both centres; the gearbox members are level across; the tank post is plumb both ways and the cradle level.

### 3.2 Pedal outrigger

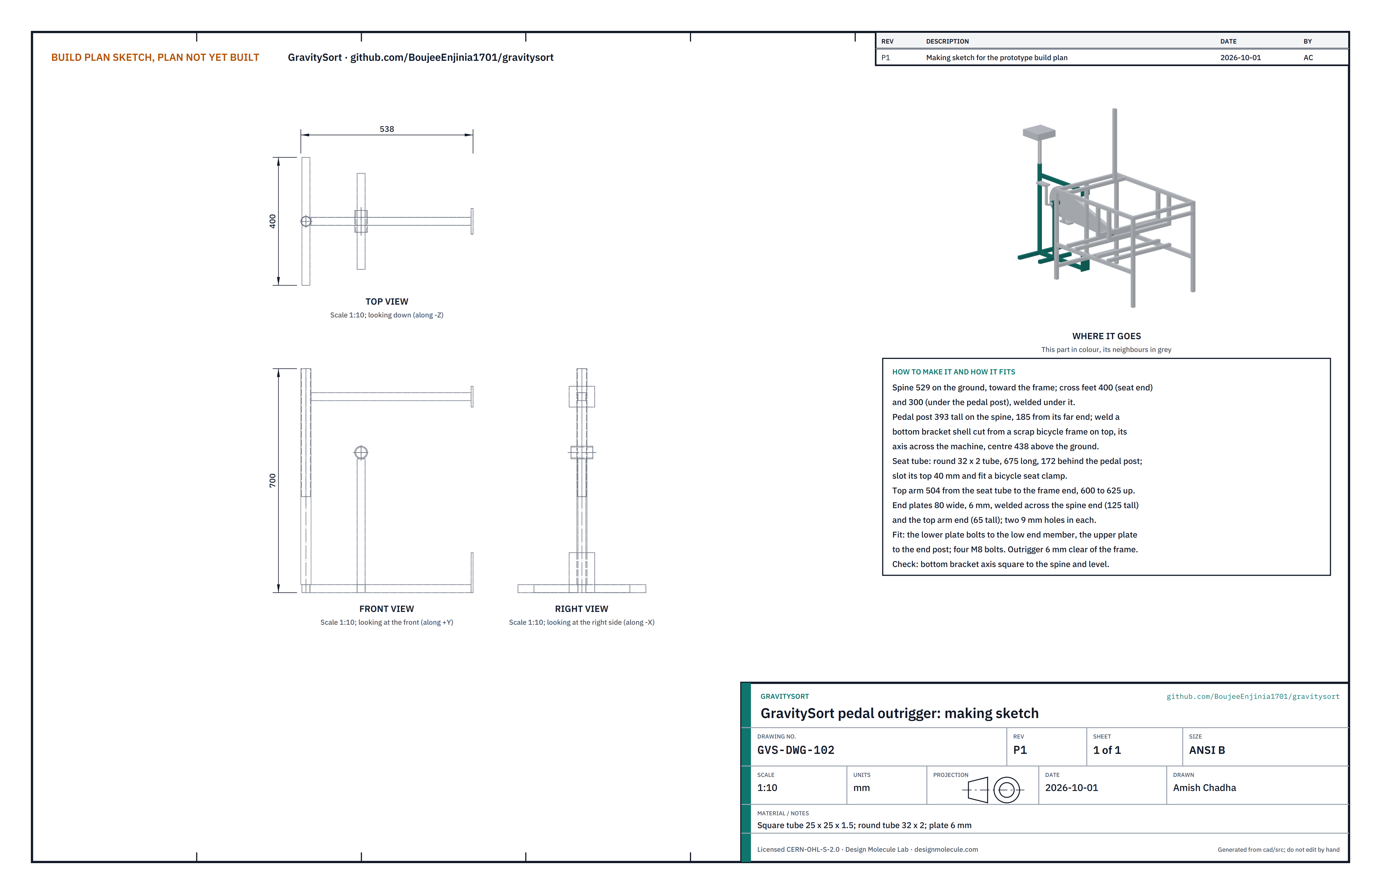
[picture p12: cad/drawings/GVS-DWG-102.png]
Figure 4. Making sketch of the pedal outrigger


*Figure 4. Pedal outrigger making sketch (GVS-DWG-102).*

**What it is and what it is made from.** The rider's seat and the bottom bracket for the crank, on a welded stand that bolts to the pedal end of the frame. Square tube 25 x 25 x 1.5 mm (2.1 m), round tube 32 x 2 mm (675 mm), plate 6 mm, and a bottom bracket shell cut from a scrap bicycle frame.

**How to make it.**

1. Cut the spine 529, the seat cross foot 400, the pedal cross foot 300, the pedal post 393 and the top arm 504.
2. Weld the two cross feet under the spine: the seat foot at the far end, the pedal foot 185 from the far end.
3. Weld the pedal post upright on the spine over the pedal foot. Weld the bottom bracket shell on top of it, its axis across the machine, centre 438 above the ground.
4. Weld the seat tube upright on the spine 172 behind the pedal post (toward the far end). Cut a 40 mm slot down its top for a bicycle seat clamp.
5. Weld the top arm from the seat tube to the frame end, 600 to 625 above the ground.
6. Weld an end plate 80 wide across the end of the spine (125 tall) and across the end of the top arm (65 tall). Drill two 9 mm holes in each to match the low end member and the end post.

**How it fits the parts next to it.**

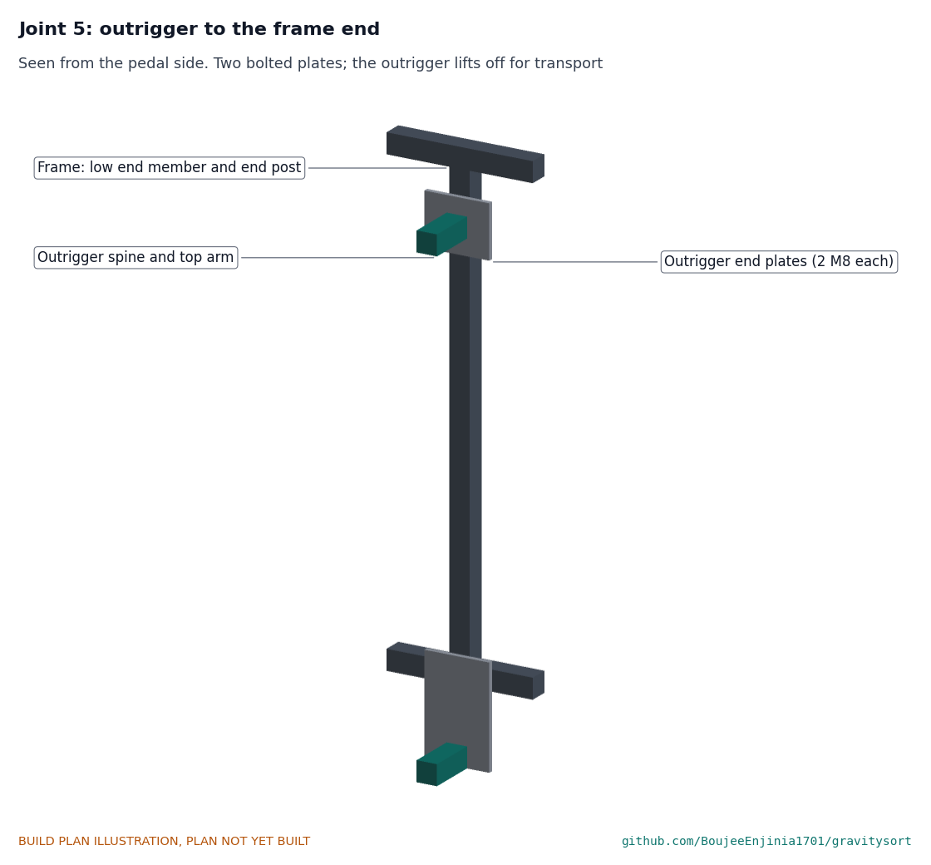
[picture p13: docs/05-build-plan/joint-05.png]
Figure 5. Joint 5: outrigger end plates on the frame end


*Figure 5. Each end plate lies flat on the frame end; two M8 bolts through each. The outrigger itself stays 6 mm clear of the frame.*

**Check before moving on.** Bolted on, the bottom bracket axis is level and square to the frame end; the outrigger stands on its feet without rocking.

### 3.3 Spindle

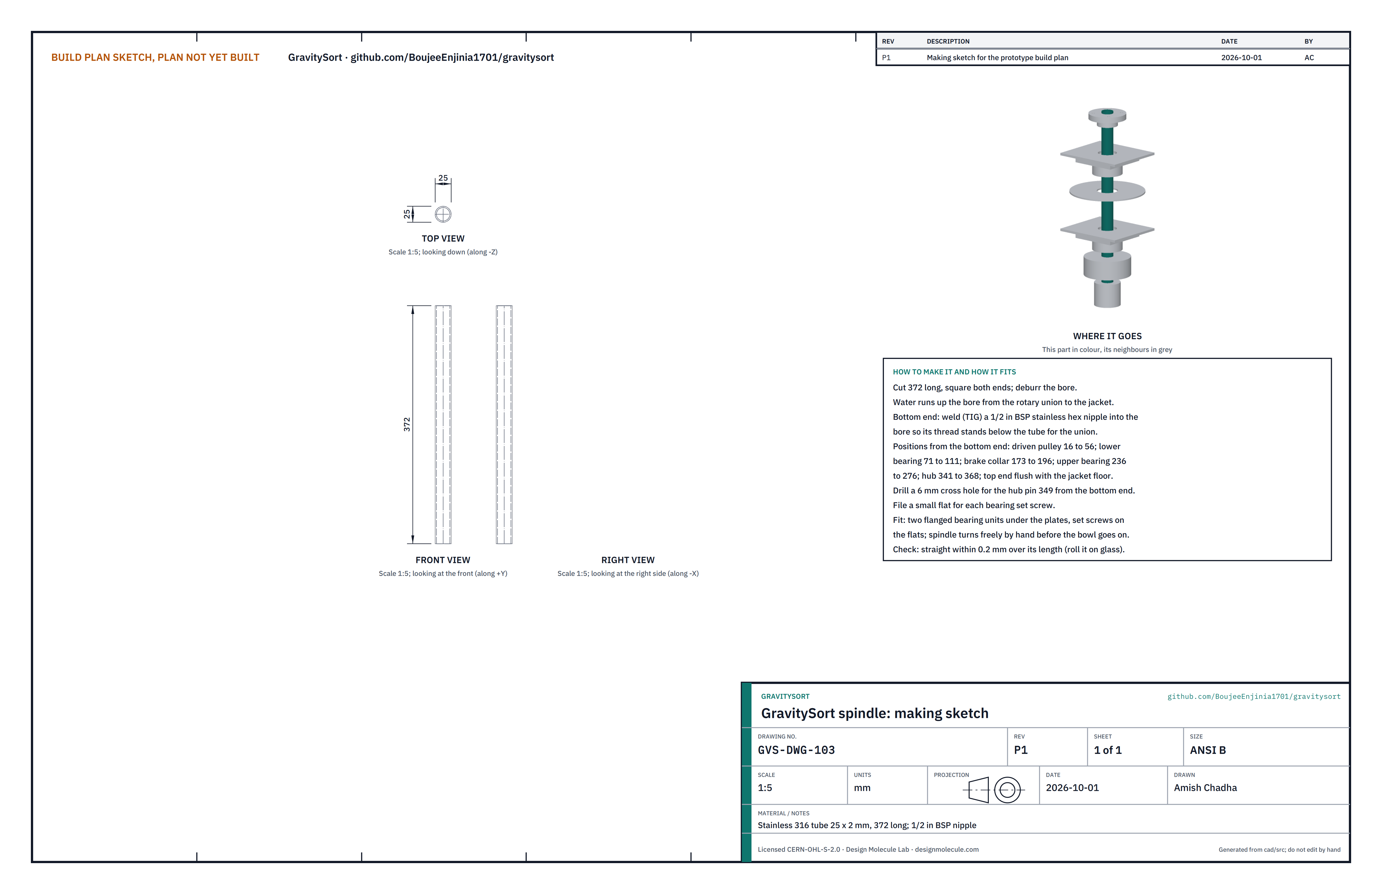
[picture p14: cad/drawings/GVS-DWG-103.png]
Figure 6. Making sketch of the spindle


*Figure 6. Spindle making sketch (GVS-DWG-103).*

**What it is and what it is made from.** The vertical shaft that carries the bowl and the brake disc, turns in two bearings and carries the fluidization water up its bore. Stainless 316 tube 25 x 2 mm, 372 long, and a 1/2 in BSP stainless hex nipple.

**How to make it.**

1. Cut 372 long; square both ends and deburr the bore.
2. TIG weld the nipple into the bottom end so its thread stands below the tube, and check that water runs through freely.
3. From the bottom end, mark: driven pulley 16 to 56; lower bearing 71 to 111; brake collar 173 to 196; upper bearing 236 to 276; hub 341 to 368.
4. Drill a 6 mm cross hole for the hub pin 349 from the bottom end. File a small flat under each bearing's set screws.

**How it fits the parts next to it.**

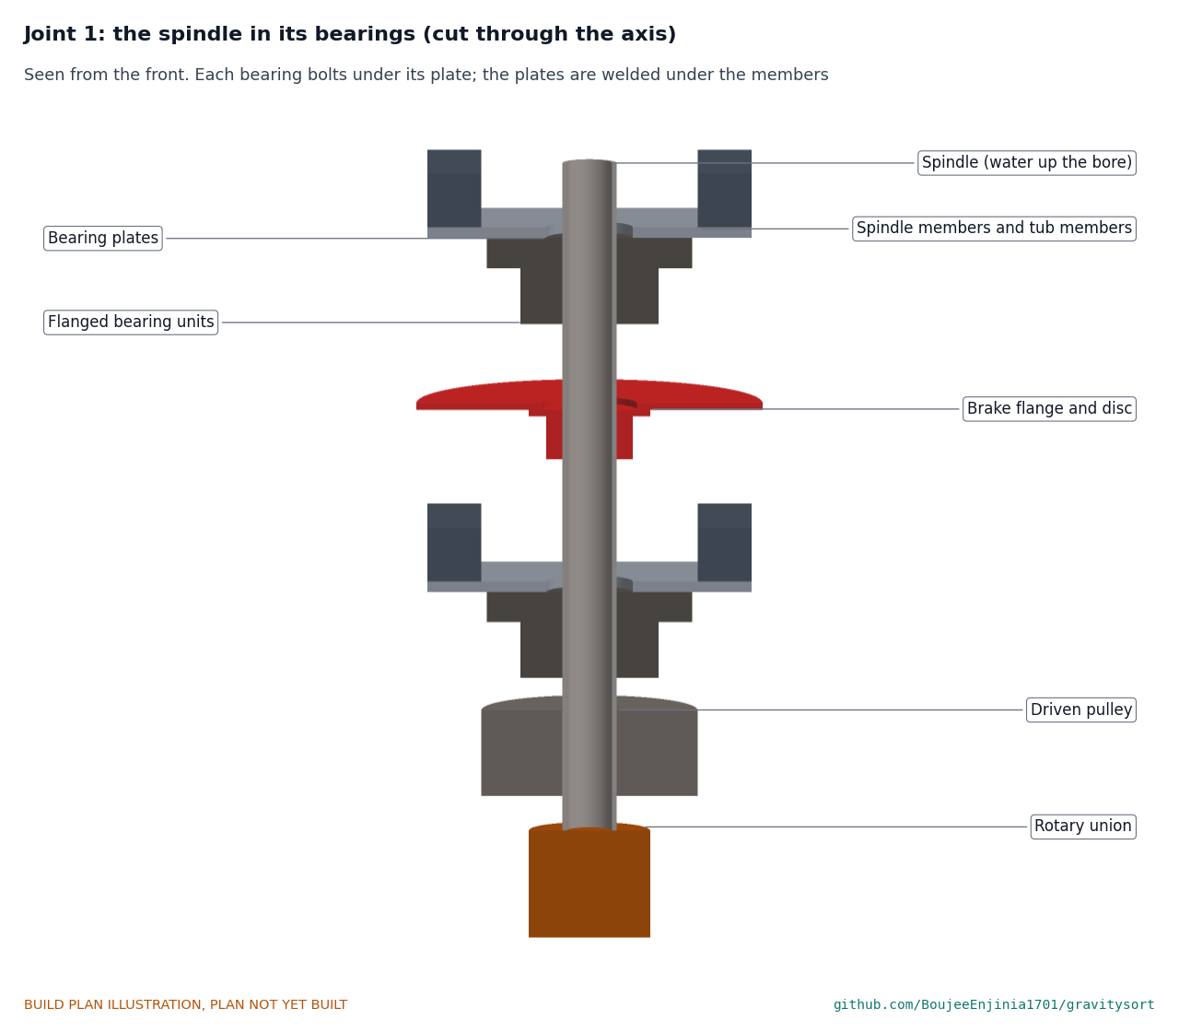
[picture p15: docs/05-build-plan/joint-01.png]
Figure 7. Joint 1: the spindle in its bearings


*Figure 7. Each bearing hangs under its plate on four M10 bolts; the brake disc runs between the two plates; the driven pulley and the rotary union are below.*

The two flanged bearing units hang under the bearing plates, 255 and 420 above the ground at their centres, and hold the spindle by their set screws on the flats. The driven pulley sits on its taper bush below the lower bearing, 180 to 220 above the ground; the rotary union screws onto the nipple below that.

**Check before moving on.** Rolled on a flat sheet of glass the spindle is straight within 0.2 mm; fitted in its bearings it turns freely by hand.

### 3.4 Brake flange and caliper bracket

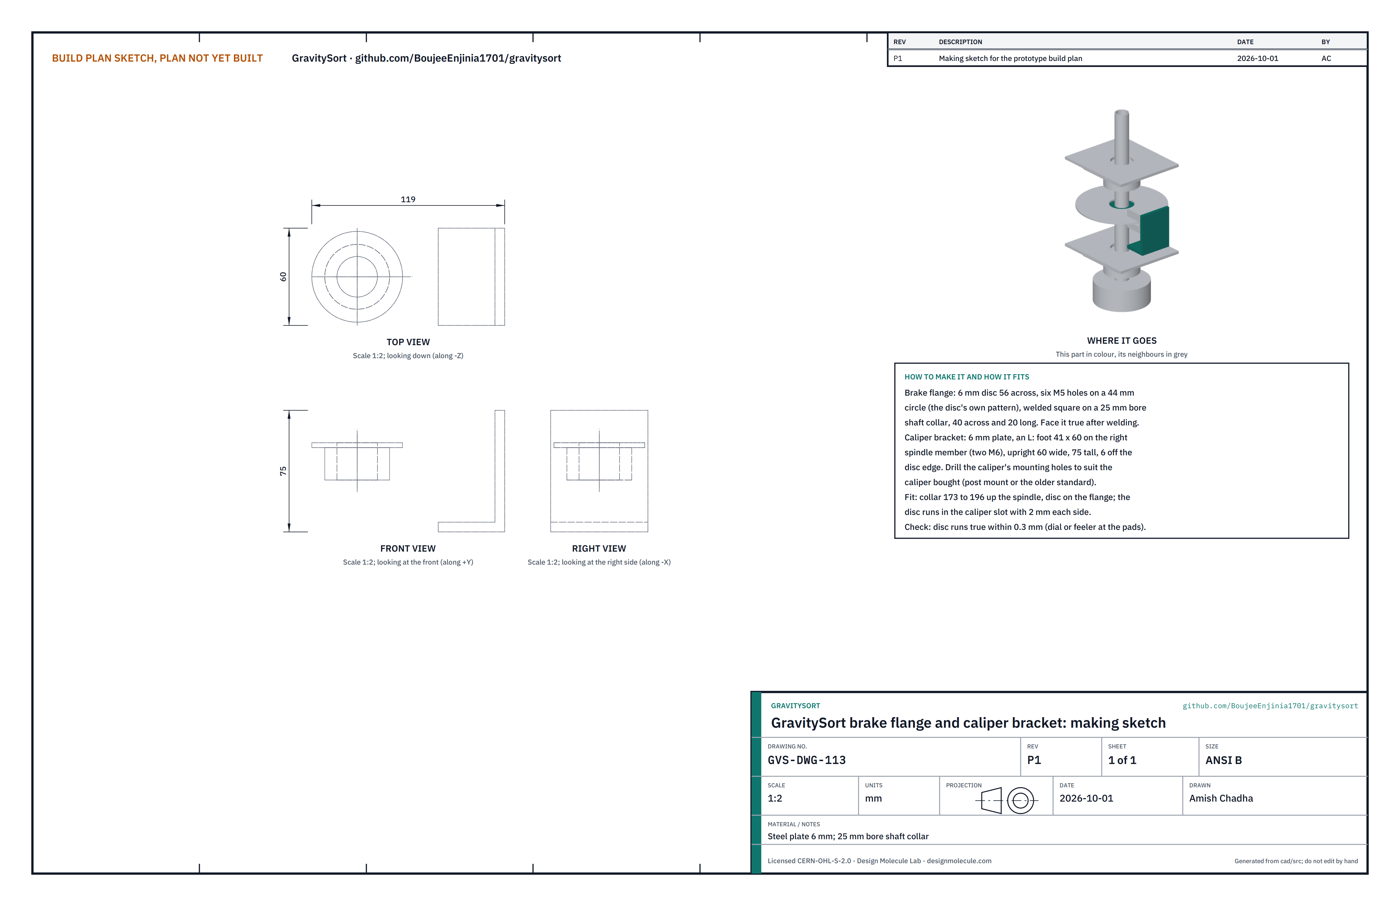
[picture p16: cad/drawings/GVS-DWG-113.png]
Figure 8. Making sketch of the brake flange and caliper bracket


*Figure 8. Brake flange and caliper bracket making sketch (GVS-DWG-113).*

**What it is and what it is made from.** The flange that carries the 160 mm bicycle brake disc on the spindle, and the bracket that holds the caliper. Steel plate 6 mm and a 25 mm bore shaft collar.

**How to make it.**

1. Flange: cut a 6 mm disc 56 across; drill six M5 holes on a 44 mm circle to match the disc. Weld it square on the collar (40 across, 20 long) and face it true.
2. Bracket: cut and bend an L of 6 mm plate, foot 41 x 60, upright 60 wide and 75 tall. Drill two 7 mm holes in the foot and the caliper's mounting holes in the upright to suit the caliper bought.

**How it fits the parts next to it.**

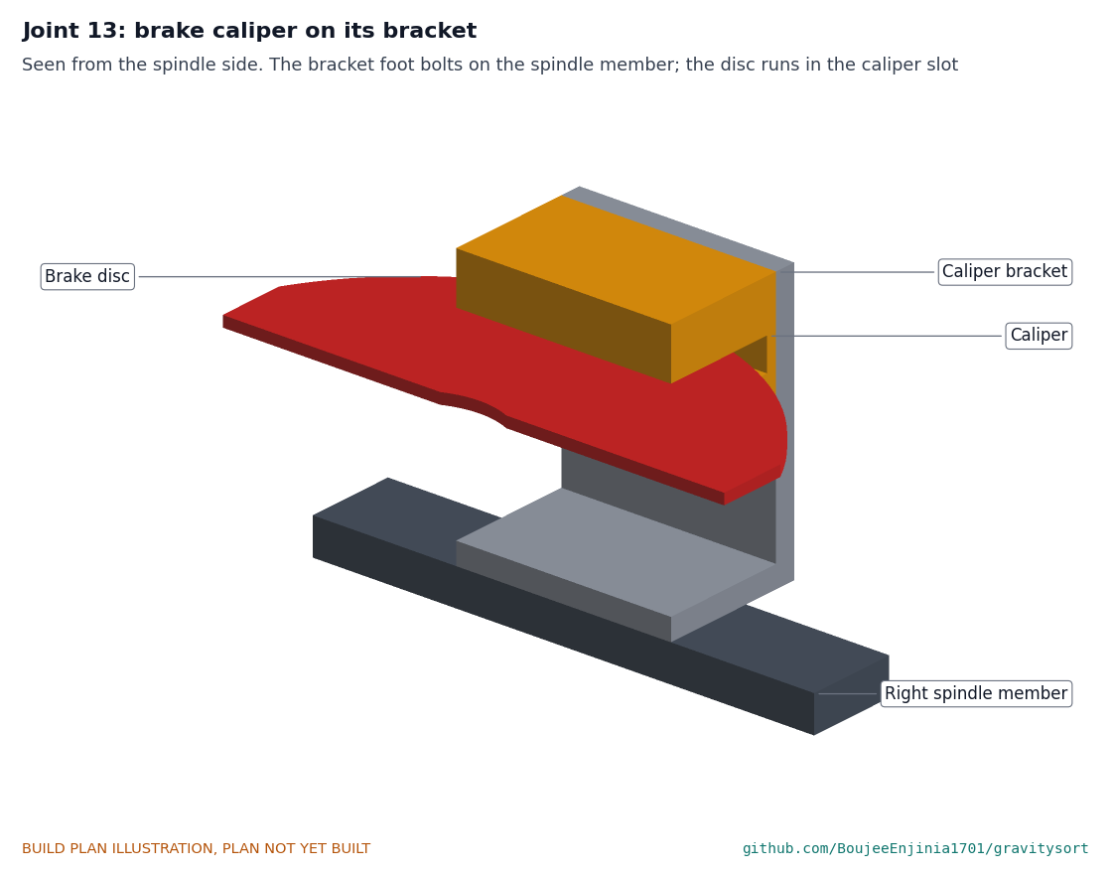
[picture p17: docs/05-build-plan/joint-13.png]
Figure 9. Joint 13: caliper on its bracket


*Figure 9. The bracket foot bolts on top of the right spindle member (two M6); the disc runs in the caliper slot.*

The collar clamps the spindle 337 to 360 above the ground; the disc sits on the flange, 360 above the ground, between the two bearing plates. The caliper bolts to the upright with 2 mm each side of the disc.

**Check before moving on.** Spun by hand the disc runs true within 0.3 mm at the pads and does not rub.

### 3.5 Bowl shell

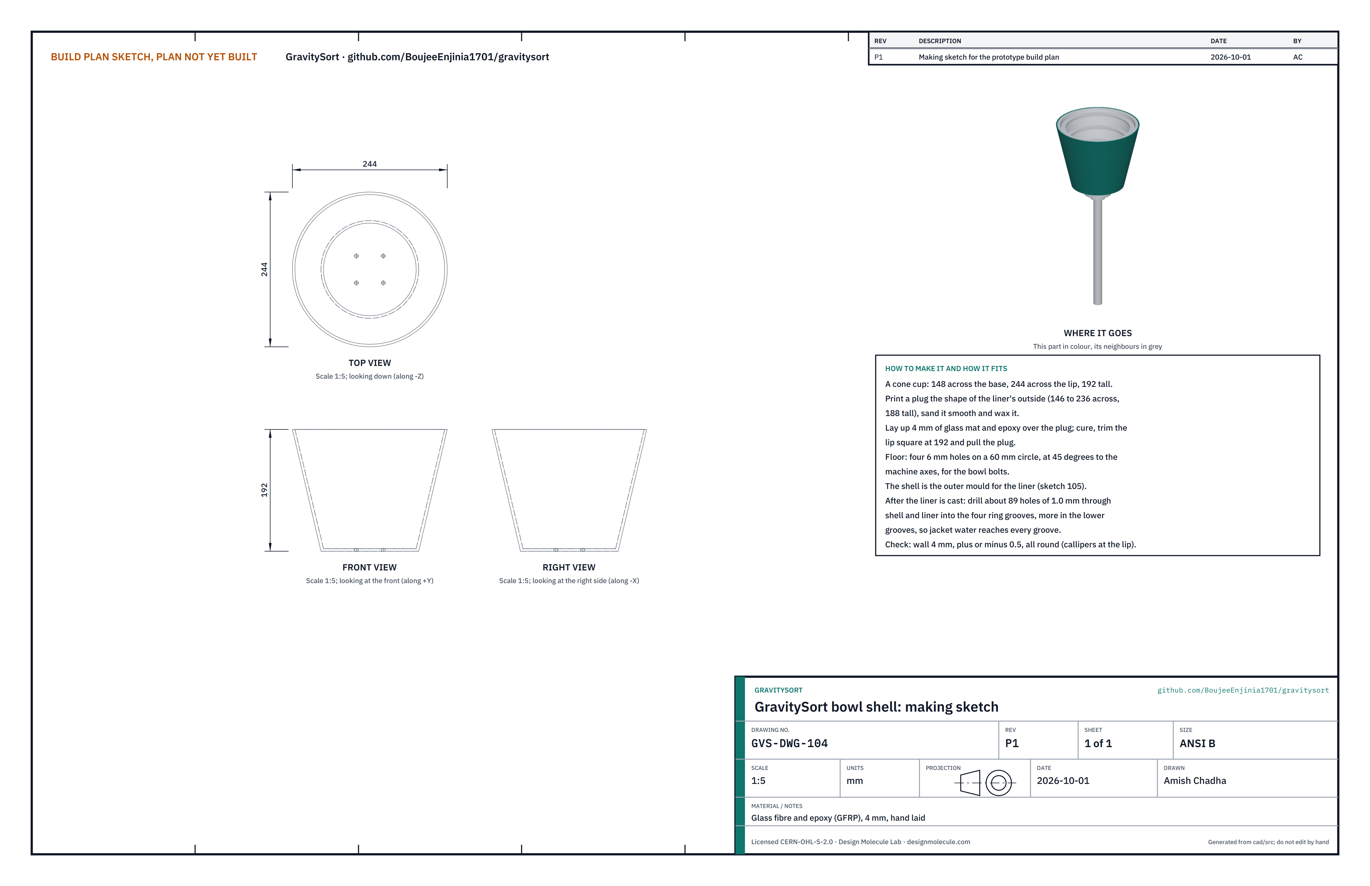
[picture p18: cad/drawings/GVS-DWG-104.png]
Figure 10. Making sketch of the bowl shell


*Figure 10. Bowl shell making sketch (GVS-DWG-104).*

**What it is and what it is made from.** The glass fibre cup that is both the outer mould for the liner and the bowl's strength. Glass mat and epoxy, 4 mm, hand laid over a printed plug.

**How to make it.**

1. Print a plug the shape of the liner's outside: 146 across the base, 236 across the top, 188 tall. Sand it smooth, seal it and wax it.
2. Lay up 4 mm of glass mat and epoxy over the plug, floor and walls. Cure as the resin maker says.
3. Trim the lip square, 192 above the outside of the floor; pull the plug.
4. Drill four 6 mm holes in the floor on a 60 mm circle, at 45 degrees to the machine's axes.

**How it fits the parts next to it.** The liner is cast inside it (section 3.6); the jacket goes round it with a 12 mm gap (section 3.7).

**Check before moving on.** The wall is 4 mm thick, give or take 0.5, all round the lip; no dry glass or air bubbles.

### 3.6 Bowl liner

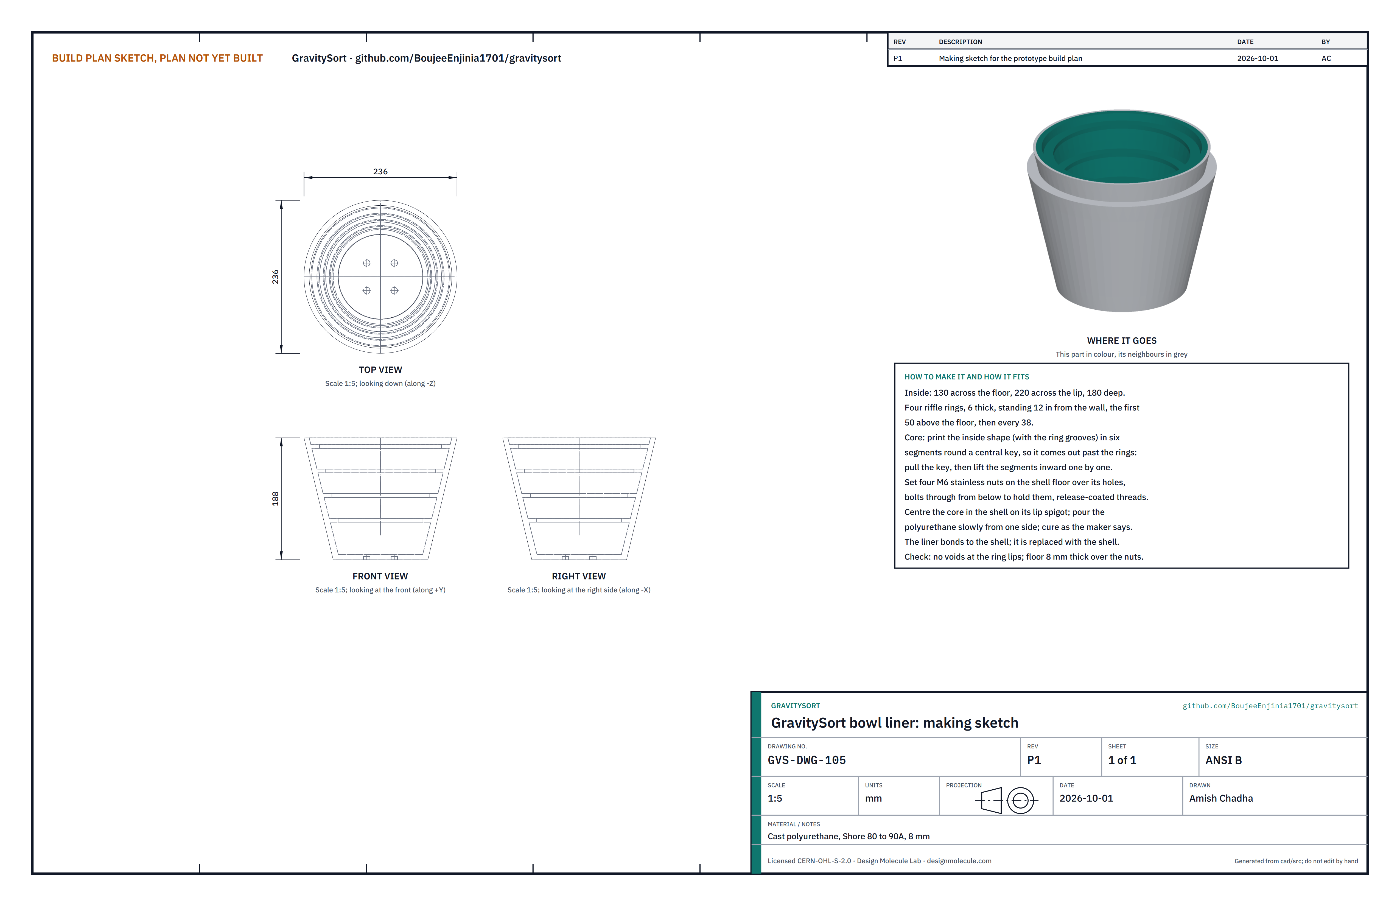
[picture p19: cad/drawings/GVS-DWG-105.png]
Figure 11. Making sketch of the bowl liner


*Figure 11. Bowl liner making sketch (GVS-DWG-105).*

**What it is and what it is made from.** The wear surface of the bowl, with the four riffle rings that hold the gold. Cast polyurethane, Shore 80 to 90A, 8 mm thick, cast inside the shell.

**How to make it.**

1. Print the core: the inside of the bowl (130 across the floor, 220 across the lip, 180 deep) with the four ring grooves, split into six segments round a central key, plus a lip spigot that centres it on the shell.
2. Set four M6 stainless nuts on the shell floor over its holes, held by bolts from below with release on their threads.
3. Coat the core with release, assemble it and centre it in the shell.
4. Mix and pour the polyurethane slowly down one side; cure as the maker says.
5. Pull the key, lift the segments inward one at a time, and take out the bolts (the nuts stay cast in).
6. Drill about 89 holes of 1.0 mm from the outside of the shell through shell and liner into the ring grooves, more in the lower grooves.

**How it fits the parts next to it.** The liner stays bonded in the shell; they are replaced together.

**Check before moving on.** Rings are 6 thick, stand 12 in from the wall and have no voids; the floor is 8 thick over the nuts; air blown into the holes comes out in every groove.

### 3.7 Fluidization jacket and hub

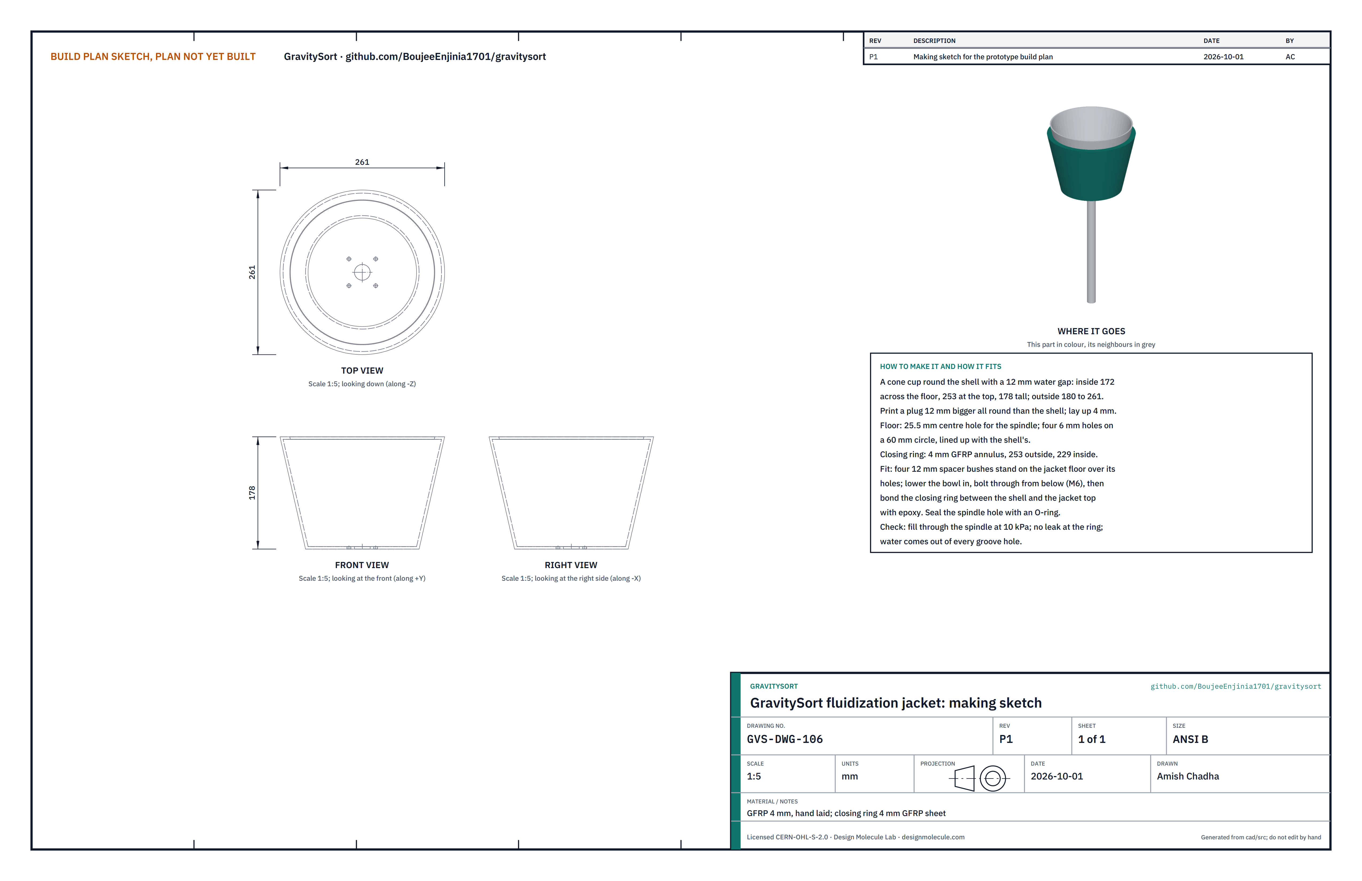
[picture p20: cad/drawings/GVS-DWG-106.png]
Figure 12. Making sketch of the fluidization jacket


*Figure 12. Fluidization jacket making sketch (GVS-DWG-106).*

**What it is and what it is made from.** The glass fibre cup round the bowl that holds the fluidization water at 12 mm from the shell, so that it is pushed through the ring holes as the bowl spins. Glass mat and epoxy, 4 mm; a closing ring of 4 mm GFRP sheet; a bought 25 mm bore shaft flange hub.

**How to make it.**

1. Print a plug 12 mm larger all round than the shell; lay up 4 mm of glass and epoxy over it; trim the top 178 above the outside of the floor.
2. Drill a 25.5 mm centre hole and four 6 mm holes on a 60 mm circle, lined up with the shell's.
3. Cut a closing ring from 4 mm GFRP sheet, 253 outside and 229 inside.
4. Drill a 6 mm cross hole through the hub's boss for the pin.

**How it fits the parts next to it.**

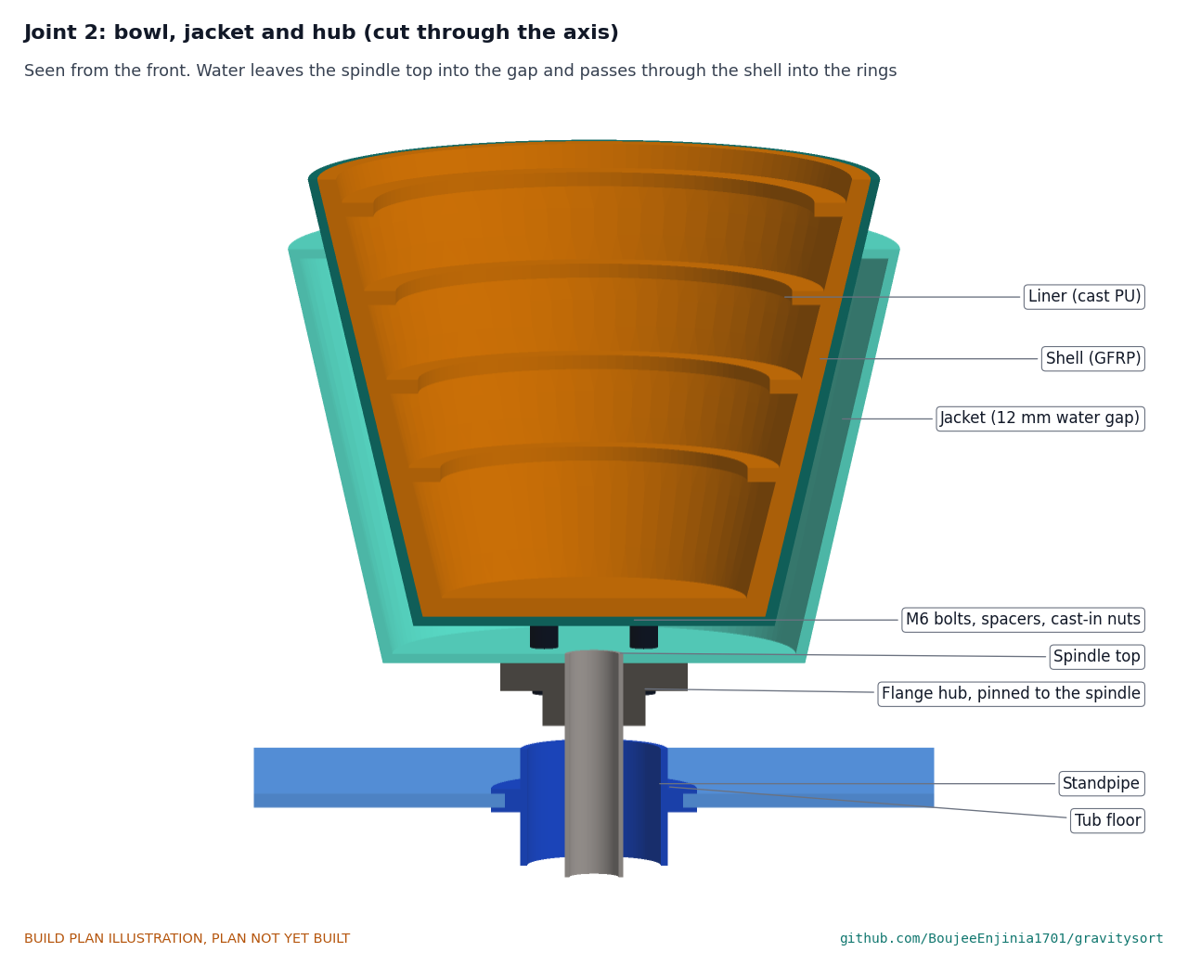
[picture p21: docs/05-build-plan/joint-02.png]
Figure 13. Joint 2: bowl, jacket and hub


*Figure 13. Four M6 bolts pass up through the hub flange, the jacket floor and four 12 mm spacer bushes into the nuts cast in the liner. The spindle's top end is flush with the jacket floor, so water leaves it into the gap.*

Stand four 12 mm spacer bushes on the jacket floor over its holes, lower the bowl in, and bolt through from below with the hub flange under the jacket floor. Bond the closing ring between the shell and the jacket's top with epoxy, and seal the spindle hole in the jacket floor with an O-ring.

**Check before moving on.** Fill the jacket through the hub at about 10 kPa (1 m of water): no leak at the closing ring, and water comes out of every groove hole. Balance the bowl group on a knife edge through the hub: it must not turn to one side.

### 3.8 Splash tub

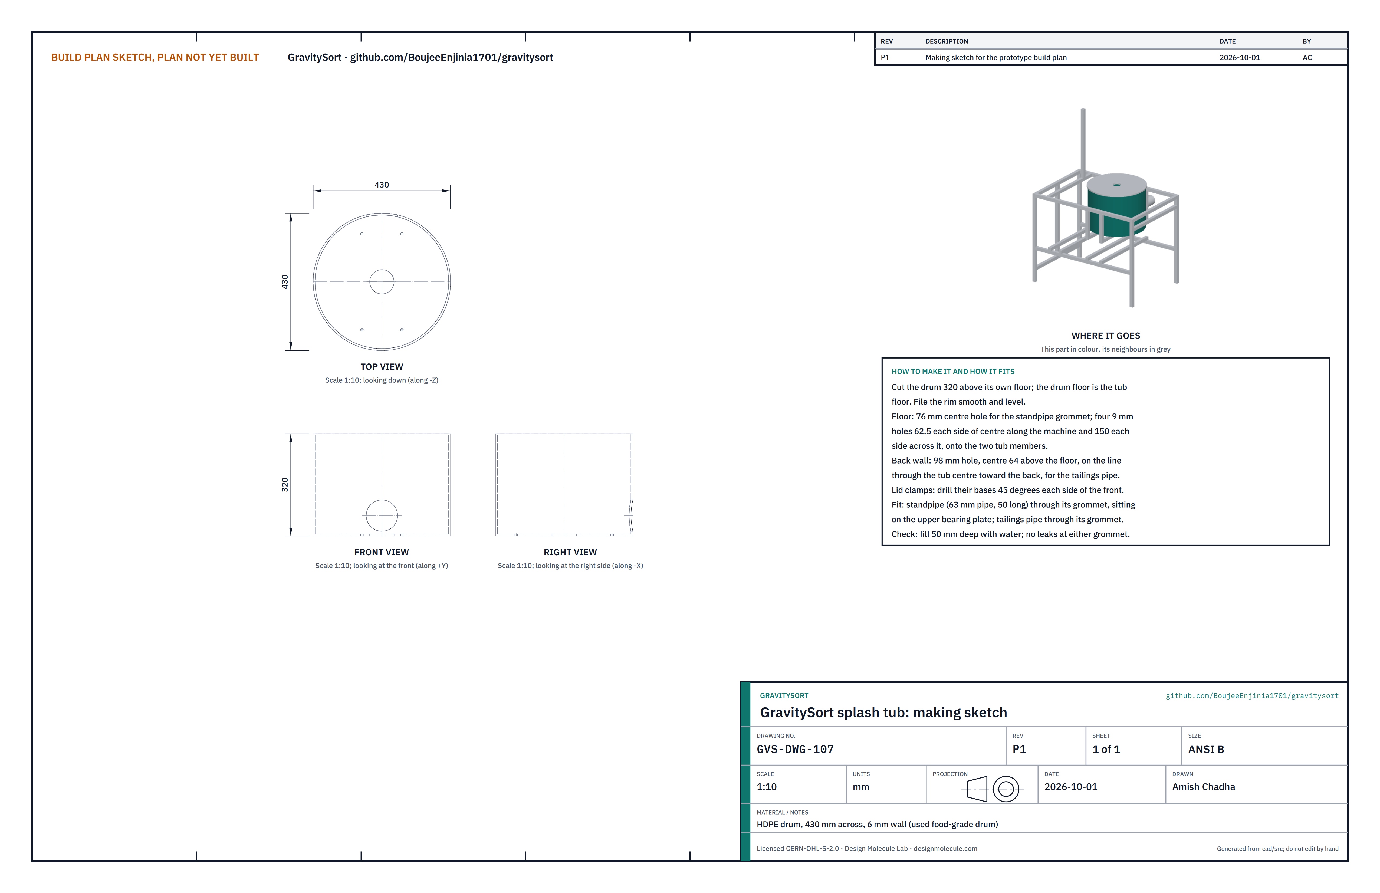
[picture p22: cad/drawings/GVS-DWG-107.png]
Figure 14. Making sketch of the splash tub


*Figure 14. Splash tub making sketch (GVS-DWG-107).*

**What it is and what it is made from.** The plastic tub round the bowl that catches the tailings thrown over the lip and sends them to the settling pond. A used HDPE drum about 430 across with a 6 mm wall, a 63 mm standpipe, a 75 mm tailings pipe and two rubber pipe grommets.

**How to make it.**

1. Cut the drum 320 above its own floor; file the rim smooth and level.
2. Floor: a 76 mm centre hole for the standpipe grommet, and four 9 mm bolt holes, 62.5 each side of centre along the machine and 150 each side across it.
3. Back wall: a 98 mm hole for the tailings pipe grommet, centre 64 above the floor, on the line from the tub centre to the back.
4. Drill the two lid clamp bases on the wall, 45 degrees each side of the front.
5. Cut the standpipe 50 long and the tailings pipe about 240 long, with a hose to the pond beyond.

**How it fits the parts next to it.**

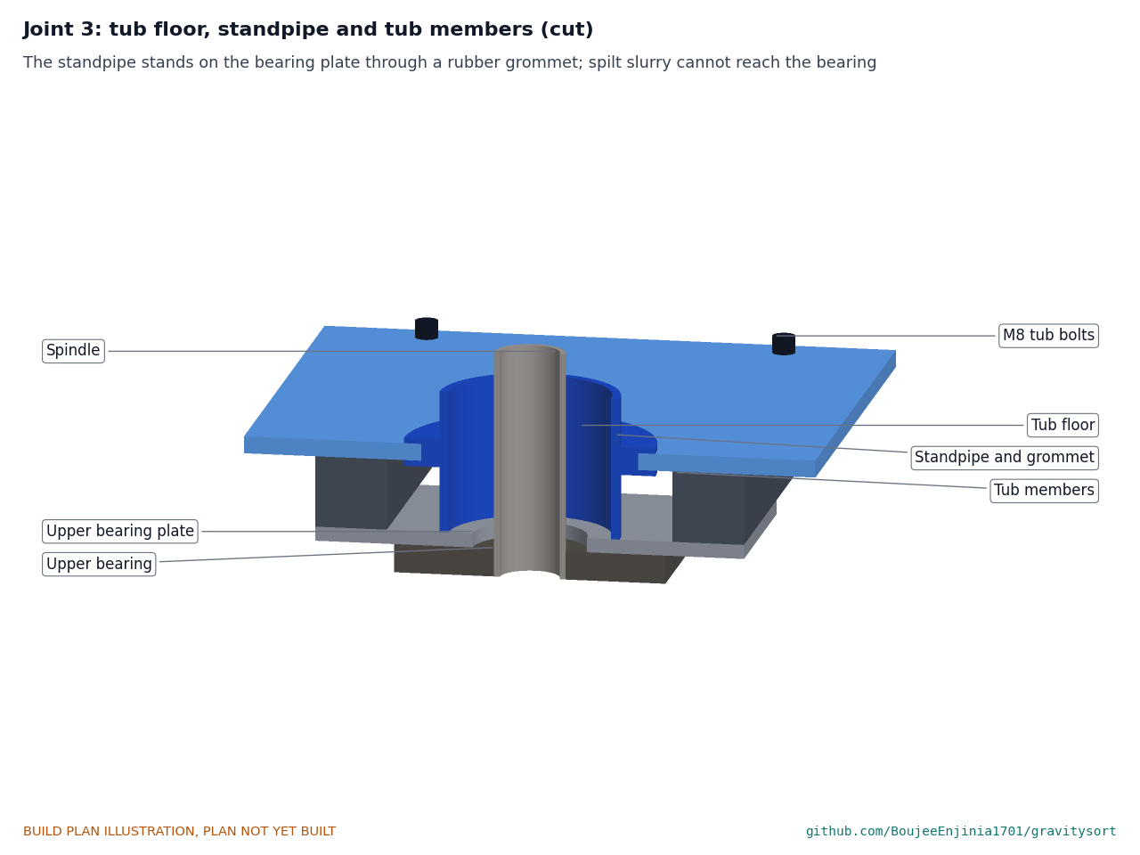
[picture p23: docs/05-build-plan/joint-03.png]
Figure 15. Joint 3: tub floor, standpipe and tub members


*Figure 15. The tub floor sits on the two tub members (four M8 bolts). The standpipe stands through its grommet on the upper bearing plate, 10 mm below the bowl hub, so slurry spilt in the tub cannot reach the bearing.*

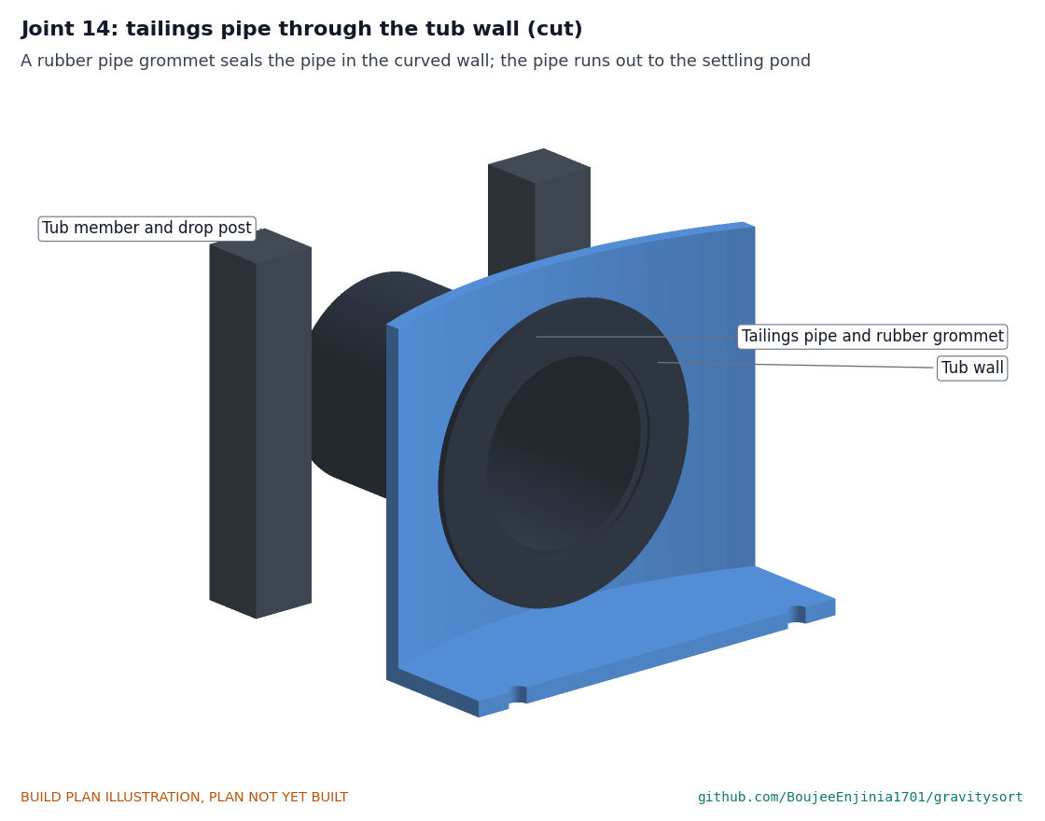
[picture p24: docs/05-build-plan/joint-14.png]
Figure 16. Joint 14: tailings pipe through the tub wall


*Figure 16. A rubber pipe grommet seals the pipe in the curved wall; the pipe runs out between the drop posts, 12 mm clear of the frame.*

**Check before moving on.** Fill the tub 50 mm deep with water: no leak at either grommet; the water runs out of the tailings pipe once it reaches the pipe.

### 3.9 Lid guard and clamps

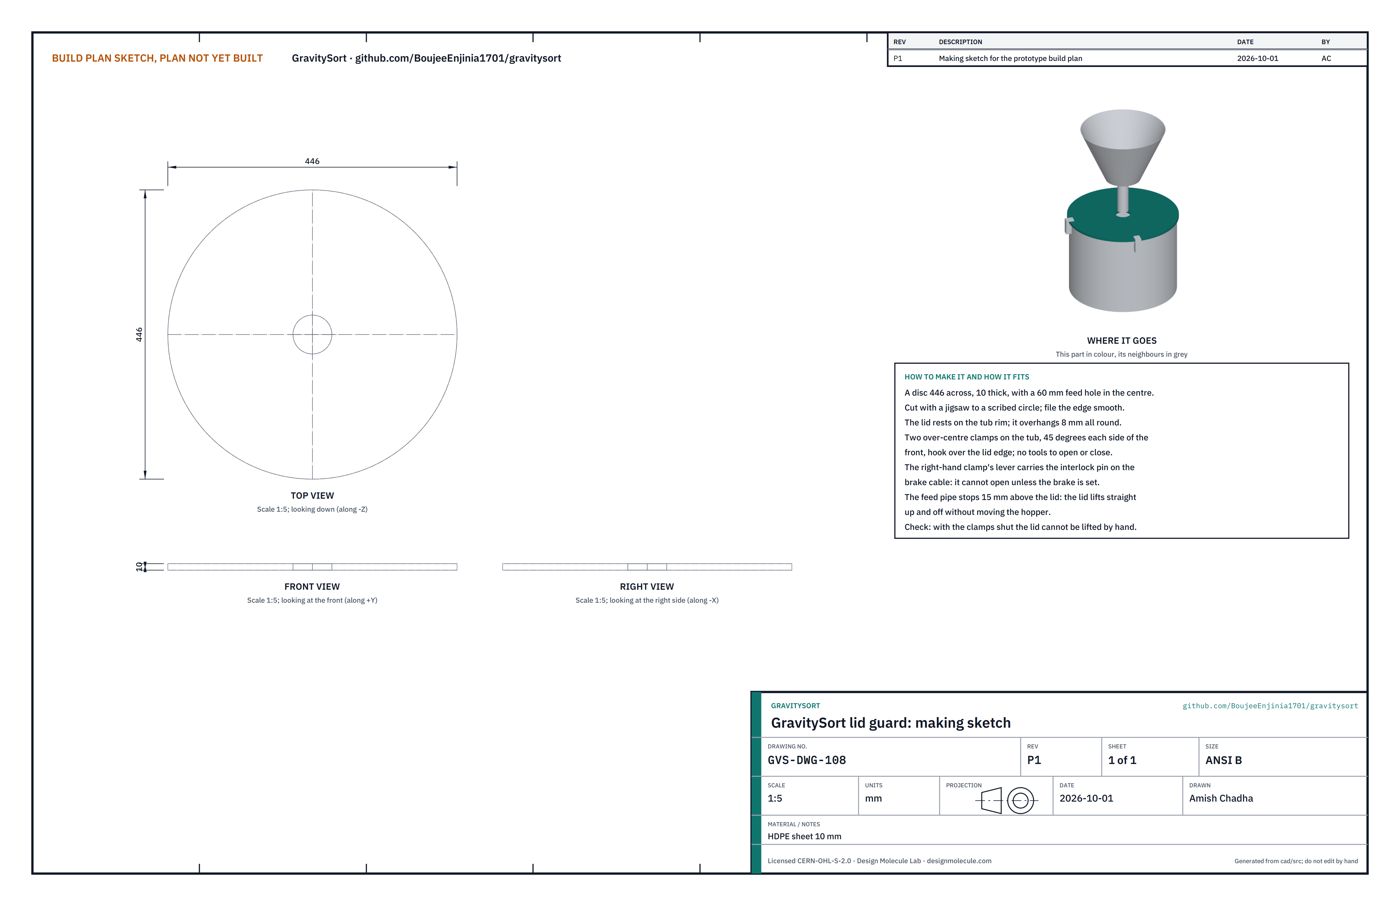
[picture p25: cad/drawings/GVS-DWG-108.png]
Figure 17. Making sketch of the lid guard


*Figure 17. Lid guard making sketch (GVS-DWG-108).*

**What it is and what it is made from.** The cover that keeps hands out of the spinning bowl and holds back splash. HDPE sheet 10 mm, and two bought over-centre toggle clamps.

**How to make it.**

1. Scribe a 446 circle and a 60 circle at its centre; cut both with a jigsaw and file the edges smooth.
2. Bolt the two clamps to the tub wall at the holes drilled in section 3.8, with their hooks over the lid edge. Drill the right-hand clamp's lever for the interlock pin on the brake cable.

**How it fits the parts next to it.**

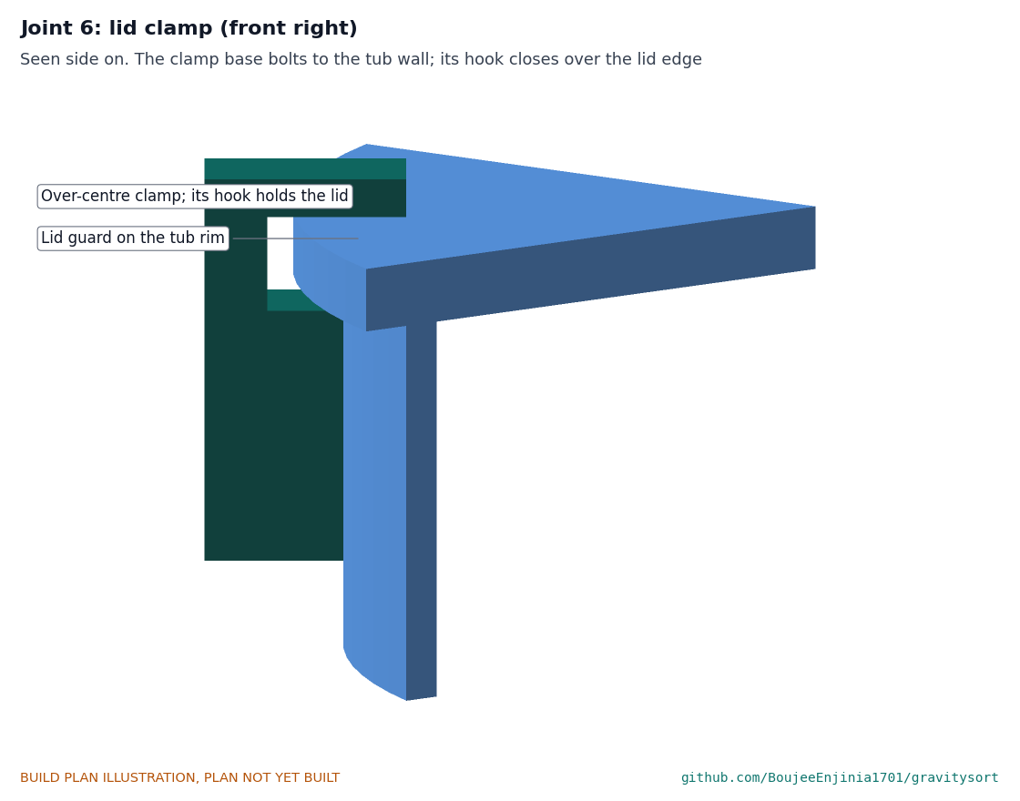
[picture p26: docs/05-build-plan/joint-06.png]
Figure 18. Joint 6: lid clamp


*Figure 18. The clamp's hook closes over the lid edge; the lid overhangs the tub rim by 8 mm all round.*

**Check before moving on.** With both clamps shut the lid cannot be lifted by hand; with the brake released, the interlock pin stops the right clamp opening.

### 3.10 Hopper support

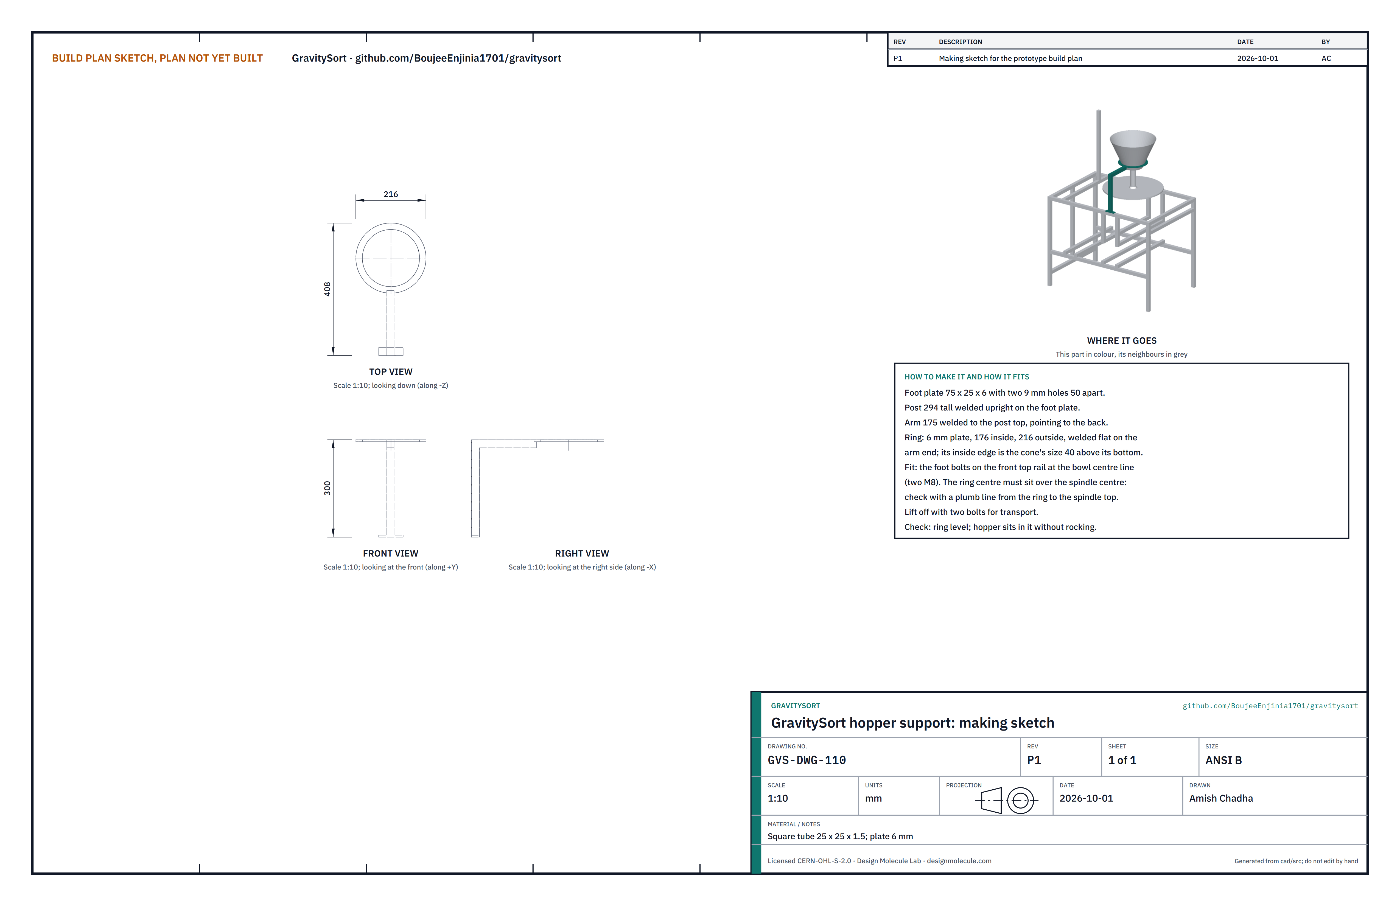
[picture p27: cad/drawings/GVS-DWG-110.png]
Figure 19. Making sketch of the hopper support


*Figure 19. Hopper support making sketch (GVS-DWG-110).*

**What it is and what it is made from.** A post, an arm and a ring that hold the hopper over the bowl. Square tube 25 x 25 x 1.5 mm and 6 mm plate.

**How to make it.**

1. Cut a foot plate 75 x 25 x 6 and drill two 9 mm holes 50 apart.
2. Weld a 294 post upright on it, and a 175 arm on the post top, pointing toward the back.
3. Cut a ring from 6 mm plate, 176 inside and 216 outside; weld it flat on the arm end.

**How it fits the parts next to it.** The foot bolts on the front top rail on the bowl's centre line (two M8). The ring centre must sit over the spindle; check with a plumb line from the ring to the spindle top. The hopper cone drops into the ring, which holds it 40 above its bottom.

**Check before moving on.** The ring is level and its centre within 3 mm of the spindle axis.

### 3.11 Hopper and screen

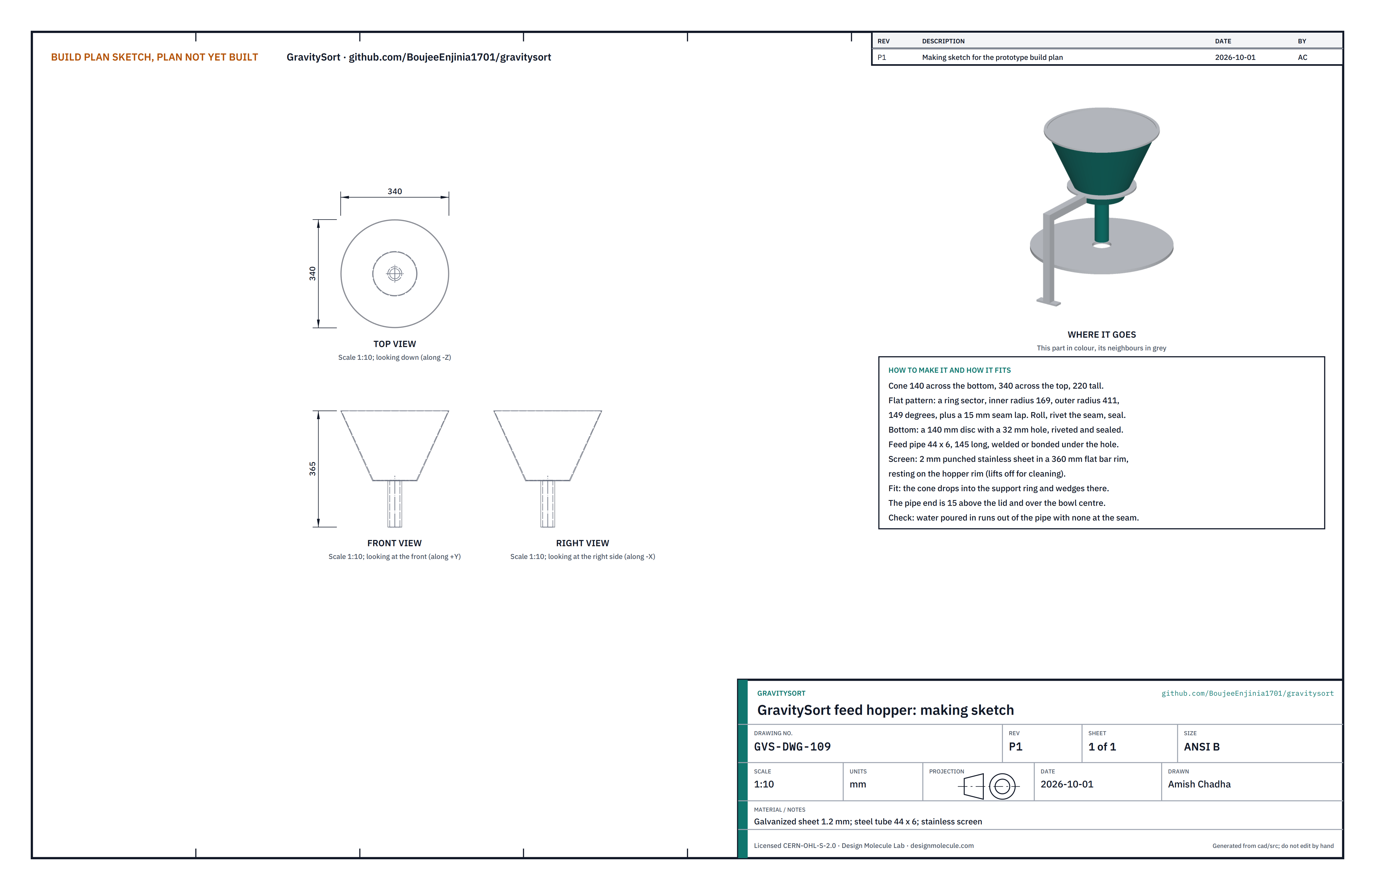
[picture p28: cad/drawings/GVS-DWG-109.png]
Figure 20. Making sketch of the hopper


*Figure 20. Feed hopper making sketch (GVS-DWG-109).*

**What it is and what it is made from.** The funnel the milled ore is shovelled into, with a 2 mm screen on top and the feed pipe below. Galvanized sheet 1.2 mm, steel tube 44 x 6 mm, 2 mm punched stainless sheet and flat bar for the screen rim.

**How to make it.**

1. Mark out the flat pattern, a ring sector of inner radius 169, outer radius 411 and 149 degrees, plus a 15 mm seam lap. Cut, roll into a cone 140 across the bottom and 340 across the top, rivet and seal the seam.
2. Rivet and seal a 140 mm bottom disc with a 32 mm centre hole.
3. Weld or bond a 145 long feed pipe under the hole.
4. Screen: roll a 360 mm ring of flat bar and fix the punched sheet inside it.

**How it fits the parts next to it.**

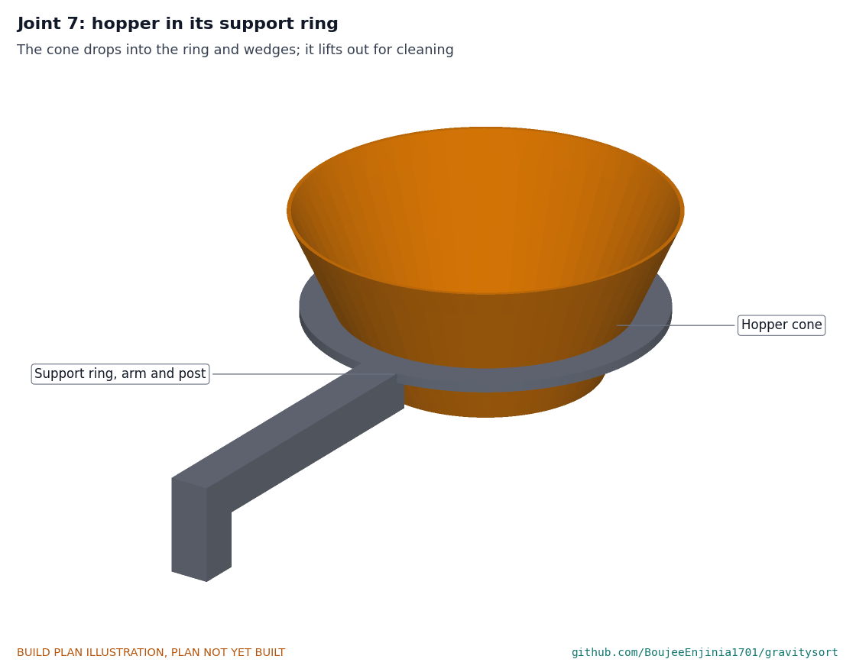
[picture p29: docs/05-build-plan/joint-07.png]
Figure 21. Joint 7: hopper in its support ring


*Figure 21. The cone drops into the ring and wedges; it lifts out for cleaning. The screen rests on the hopper rim.*

The feed pipe ends 15 above the lid, over the bowl centre: the slurry falls through the lid's hole onto the bowl floor, and the lid lifts off without touching the hopper.

**Check before moving on.** Water poured in runs out of the pipe and not at the seam; the pipe end is 15 mm, give or take 3, above the lid.

### 3.12 Bowl belt guard

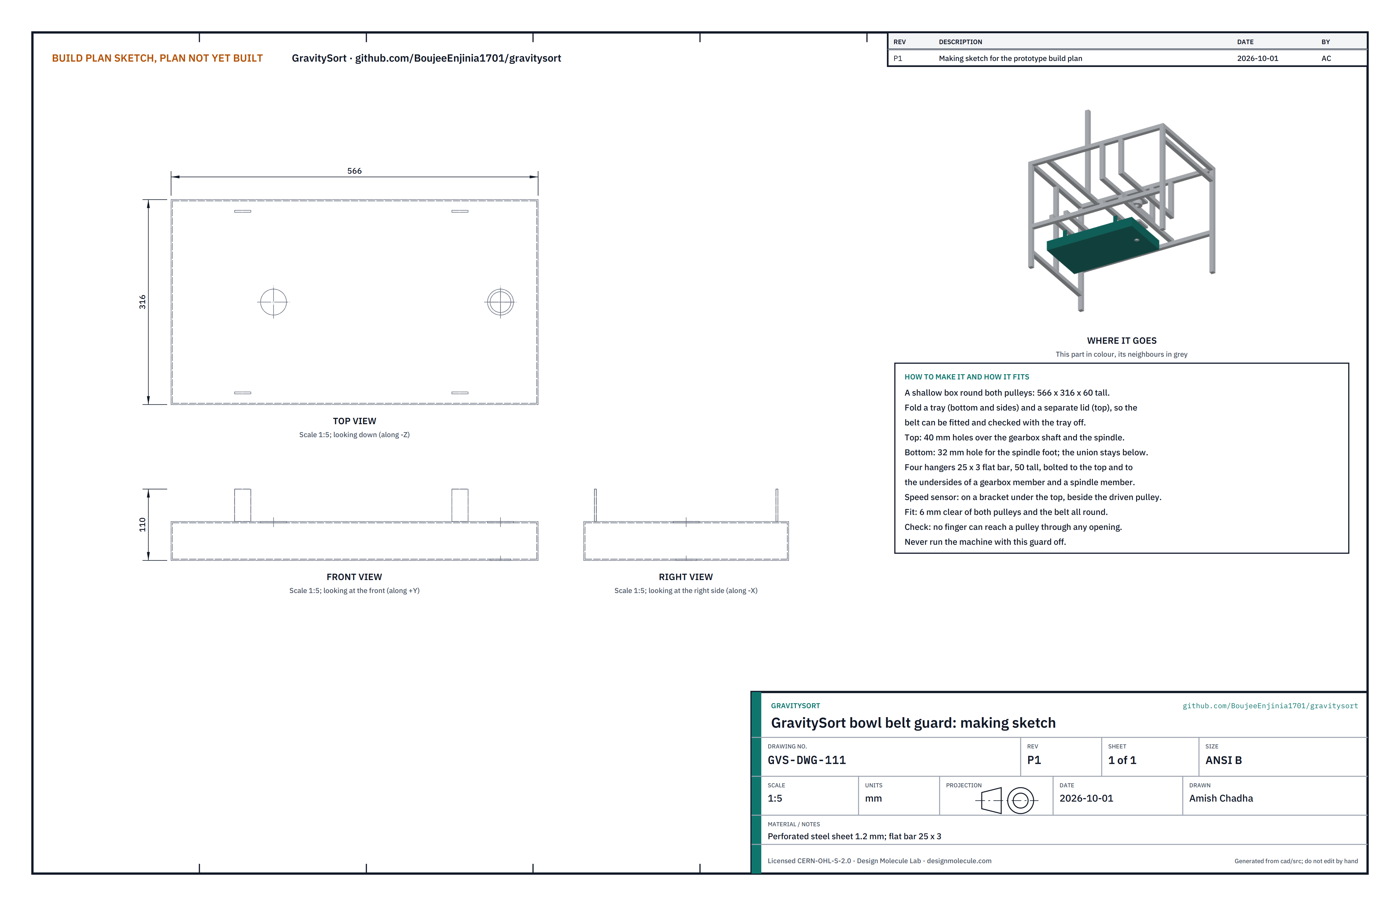
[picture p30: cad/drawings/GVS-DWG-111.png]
Figure 22. Making sketch of the bowl belt guard


*Figure 22. Bowl belt guard making sketch (GVS-DWG-111).*

**What it is and what it is made from.** A shallow box under the frame round the two bowl drive pulleys and their belt. Perforated steel sheet 1.2 mm and flat bar 25 x 3 mm.

**How to make it.**

1. Fold a tray (bottom and four sides) 566 x 316 x 60 and a separate top panel.
2. Cut a 40 mm hole in the top over the gearbox shaft and another over the spindle, and a 32 mm hole in the bottom for the spindle foot.
3. Cut four hangers 50 long from flat bar; bend a tab on each end and drill them.
4. Fix the speed sensor's bracket under the top, beside the driven pulley.

**How it fits the parts next to it.** The four hangers bolt to the top and up to the undersides of the left gearbox member and the left spindle member. The guard stays 6 mm clear of both pulleys and the belt, 5 mm below the lower bearing and above the rotary union.

**Check before moving on.** No finger can reach a pulley or the belt through any opening; the tray comes off without moving the top.

### 3.13 Pedal chain case

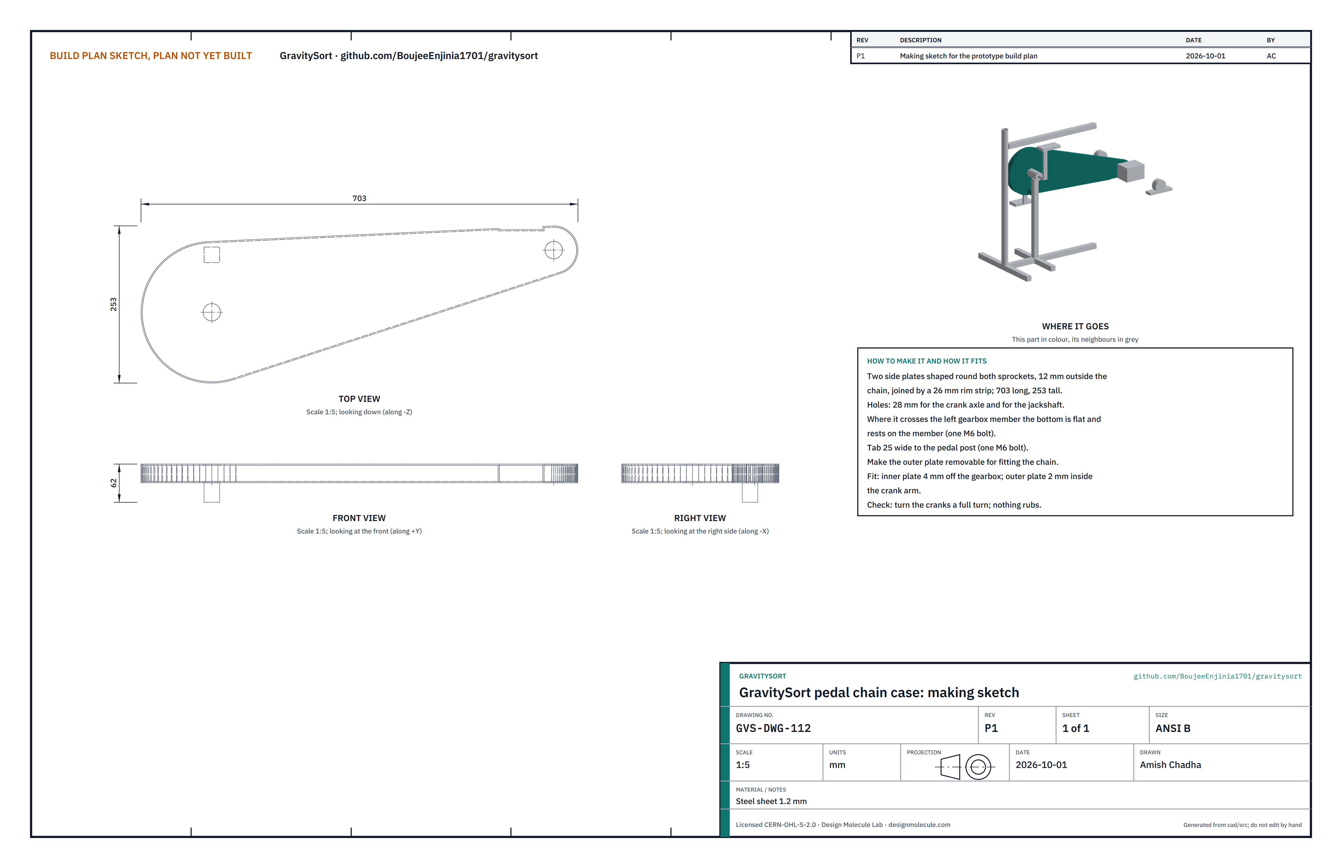
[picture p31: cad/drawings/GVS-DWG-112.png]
Figure 23. Making sketch of the pedal chain case


*Figure 23. Pedal chain case making sketch (GVS-DWG-112).*

**What it is and what it is made from.** A closed sheet case round the pedal chain from the chainring to the freewheel. Steel sheet 1.2 mm.

**How to make it.**

1. Cut two side plates to the outline of Figure 23 (round both sprockets, 12 mm outside the chain), 703 long and 253 tall.
2. Cut 28 mm holes in both plates for the crank axle and the jackshaft.
3. Join the plates with a rim strip 26 wide, leaving the bottom flat where it crosses the left gearbox member. Make the outer plate removable (screws into tabs on the rim).
4. Fold a tab 25 wide for the pedal post.

**How it fits the parts next to it.**

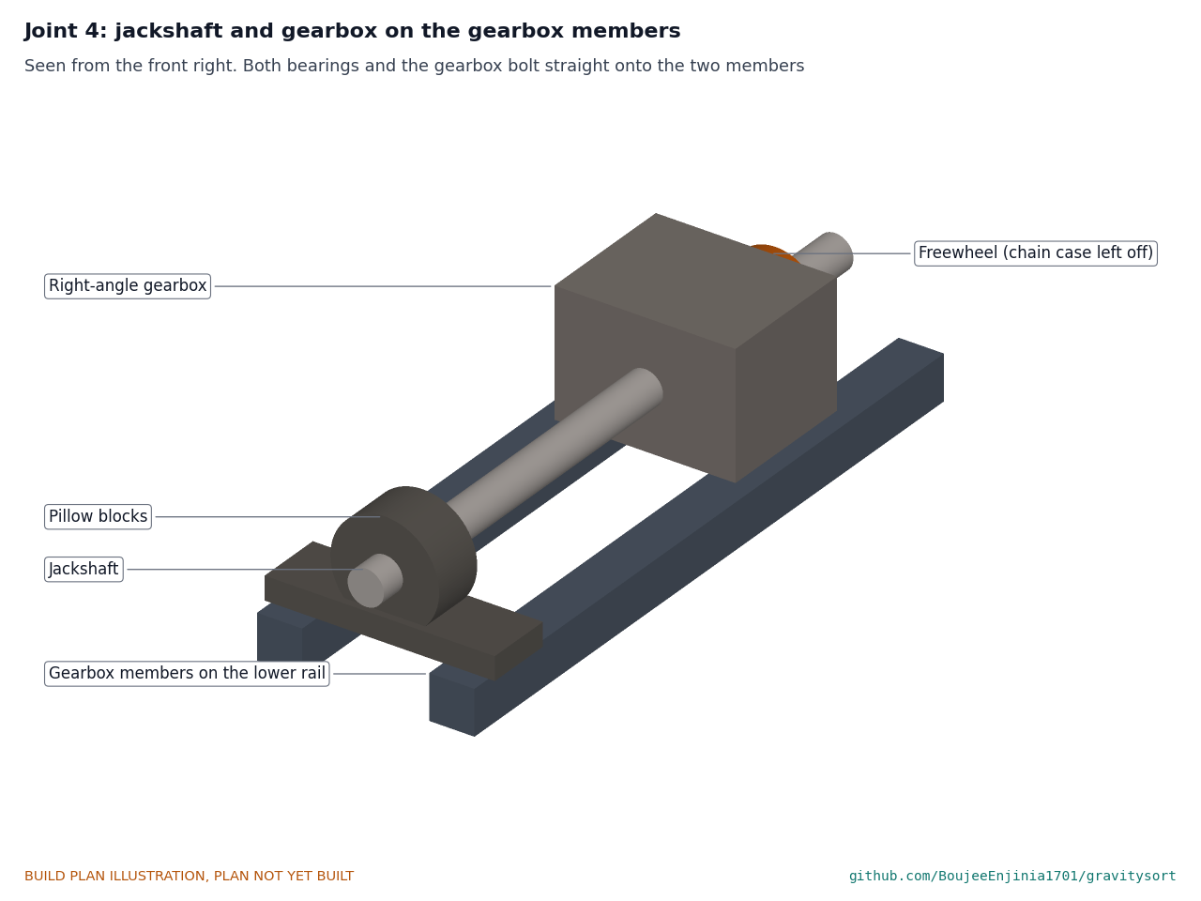
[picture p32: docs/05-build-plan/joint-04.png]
Figure 24. Joint 4: jackshaft and gearbox on the gearbox members


*Figure 24. The two pillow blocks and the gearbox bolt straight onto the two gearbox members; the chain case (left off here) rests on the left member.*

The case rests on the left gearbox member (one M6 bolt) and is tabbed to the pedal post (one M6). Its inner plate is 4 mm from the gearbox; its outer plate is 2 mm inside the right crank arm.

**Check before moving on.** Turn the cranks a full turn: nothing rubs, and the chain does not touch the case.

### 3.14 Table base and flexure legs

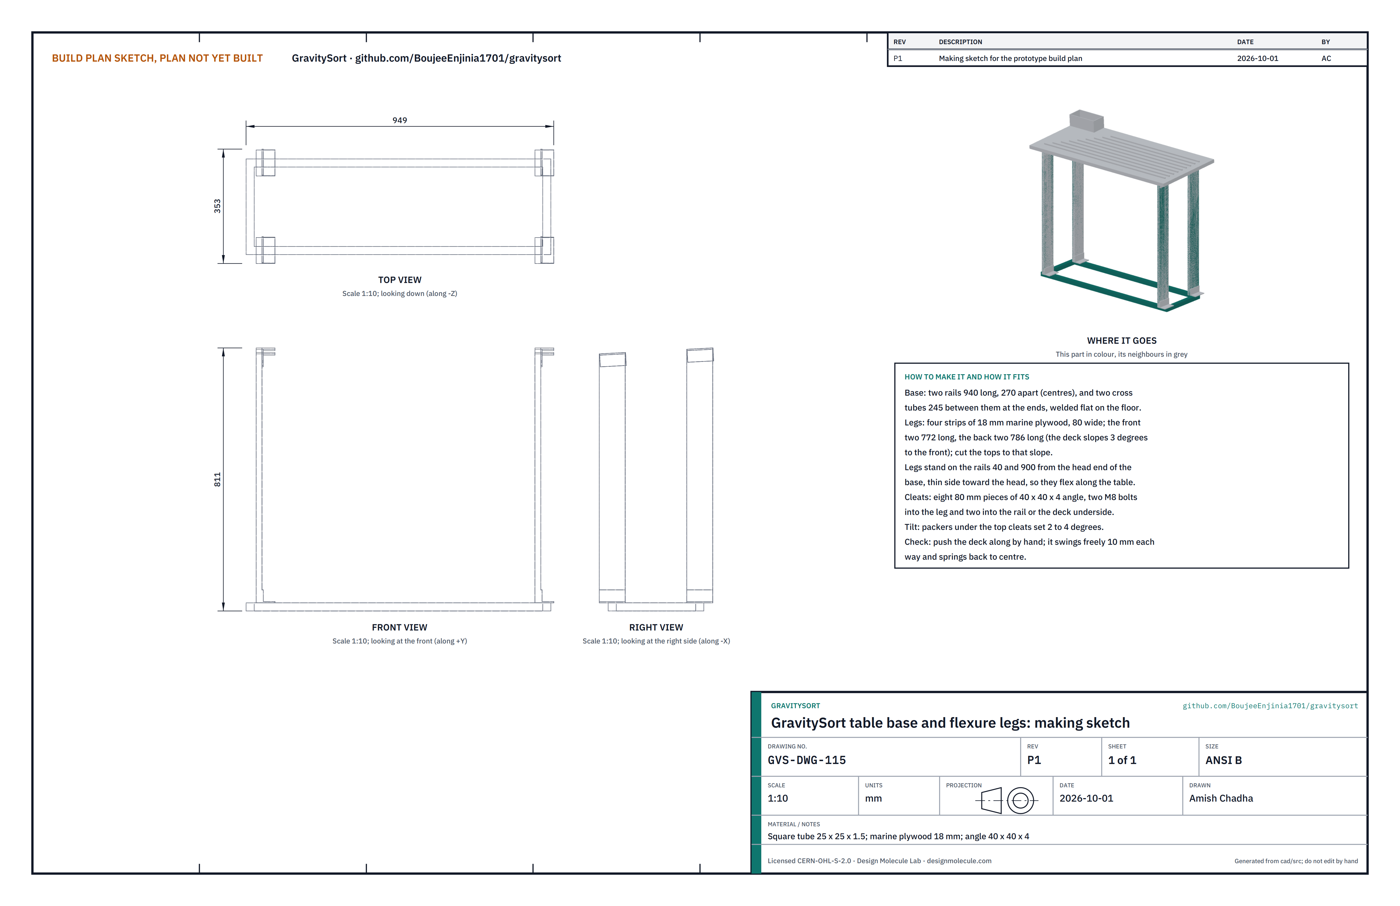
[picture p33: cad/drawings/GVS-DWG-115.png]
Figure 25. Making sketch of the table base and flexure legs


*Figure 25. Table base and flexure legs making sketch (GVS-DWG-115).*

**What it is and what it is made from.** The stand of the shaking table: a welded base on the ground and four plywood legs that bend as the deck shakes along the table. Square tube 25 x 25 x 1.5 mm (2.4 m), marine plywood 18 mm, angle 40 x 40 x 4 mm.

**How to make it.**

1. Cut two base rails 940 and two cross tubes 245; weld them flat into a rectangle with the rails 270 apart at their centres.
2. Cut four legs 80 wide from 18 mm marine plywood: the front two 772 long, the back two 786 (the deck slopes 3 degrees to the front). Cut each top to that slope. Seal the edges.
3. Cut eight cleats 80 long from the angle; drill each for two M8 bolts in each leg.

**How it fits the parts next to it.**

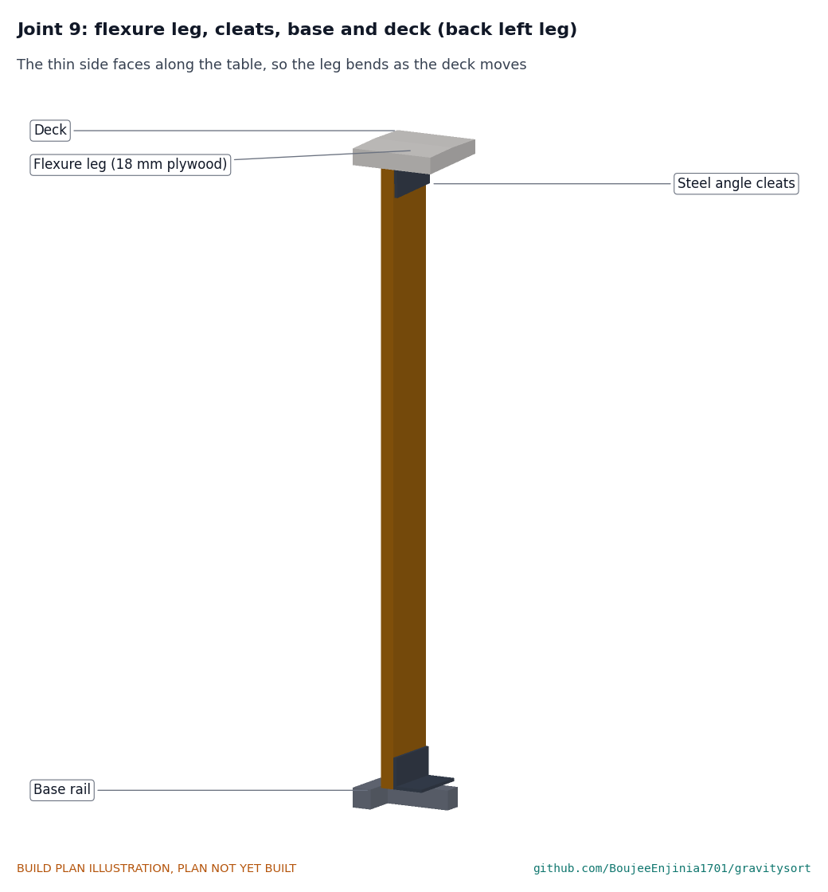
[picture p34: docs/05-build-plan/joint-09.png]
Figure 26. Joint 9: flexure leg, cleats, base and deck


*Figure 26. The thin side of each leg faces along the table, so the leg bends as the deck moves 15 mm.*

The legs stand on the rails 40 and 900 from the head end of the base. A cleat bolts each leg's foot to the rail and each leg's top to the underside of the deck. Packers under the top cleats set the deck slope between 2 and 4 degrees.

**Check before moving on.** With the deck on, push it along by hand: it moves about 10 mm each way and springs back to the middle; it does not rock across.

### 3.15 Table deck

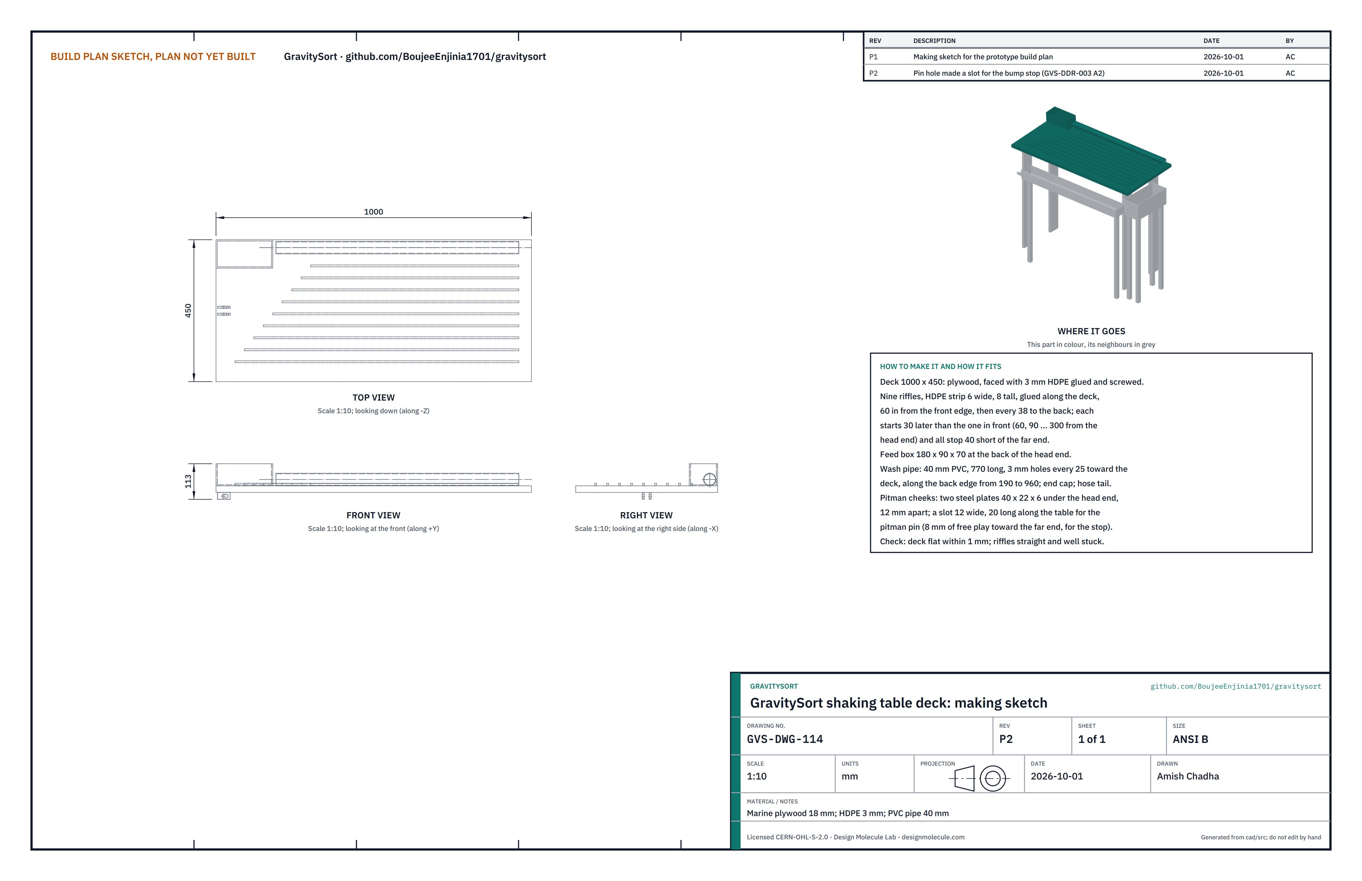
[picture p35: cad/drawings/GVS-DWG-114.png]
Figure 27. Making sketch of the table deck


*Figure 27. Shaking table deck making sketch (GVS-DWG-114).*

**What it is and what it is made from.** The riffled top that sorts the bowl concentrate by density. Marine plywood 18 mm, HDPE sheet 3 mm and strip, 40 mm PVC pipe, two small steel plates.

**How to make it.**

1. Cut the deck 1000 x 450; glue and screw 3 mm HDPE over its top.
2. Glue nine riffles of HDPE strip, 6 wide and 8 tall, along the deck, the first 60 in from the front edge and the rest every 38. Each starts 30 later than the one in front (60, 90 and so on up to 300 from the head end) and all stop 40 short of the far end.
3. Build a feed box 180 x 90 x 70 at the back of the head end.
4. Drill a 40 mm PVC pipe with 3 mm holes every 25, cap one end, fit a hose tail on the other, and clip it along the back edge from 190 to 960 from the head end.
5. Screw two steel cheeks 40 x 22 x 6, 12 apart, under the head end on the centre line. Cut a slot through both for the pitman pin, 12 wide and 20 long along the table, so the pin has 8 mm of free play toward the far end: drill two 12 mm holes 8 apart and file out the web between them.

**How it fits the parts next to it.** The deck sits on the four leg tops; the pitman pin joins its cheeks to the head (section 3.17); the striker of the bump stop screws under its head end at the back edge (section 3.16); the launder runs under its front edge and the concentrate box under its far end (section 3.18).

**Check before moving on.** The deck is flat within 1 mm across each diagonal; the riffles are straight and well stuck.

### 3.16 Table head plate, shelf and bump stop

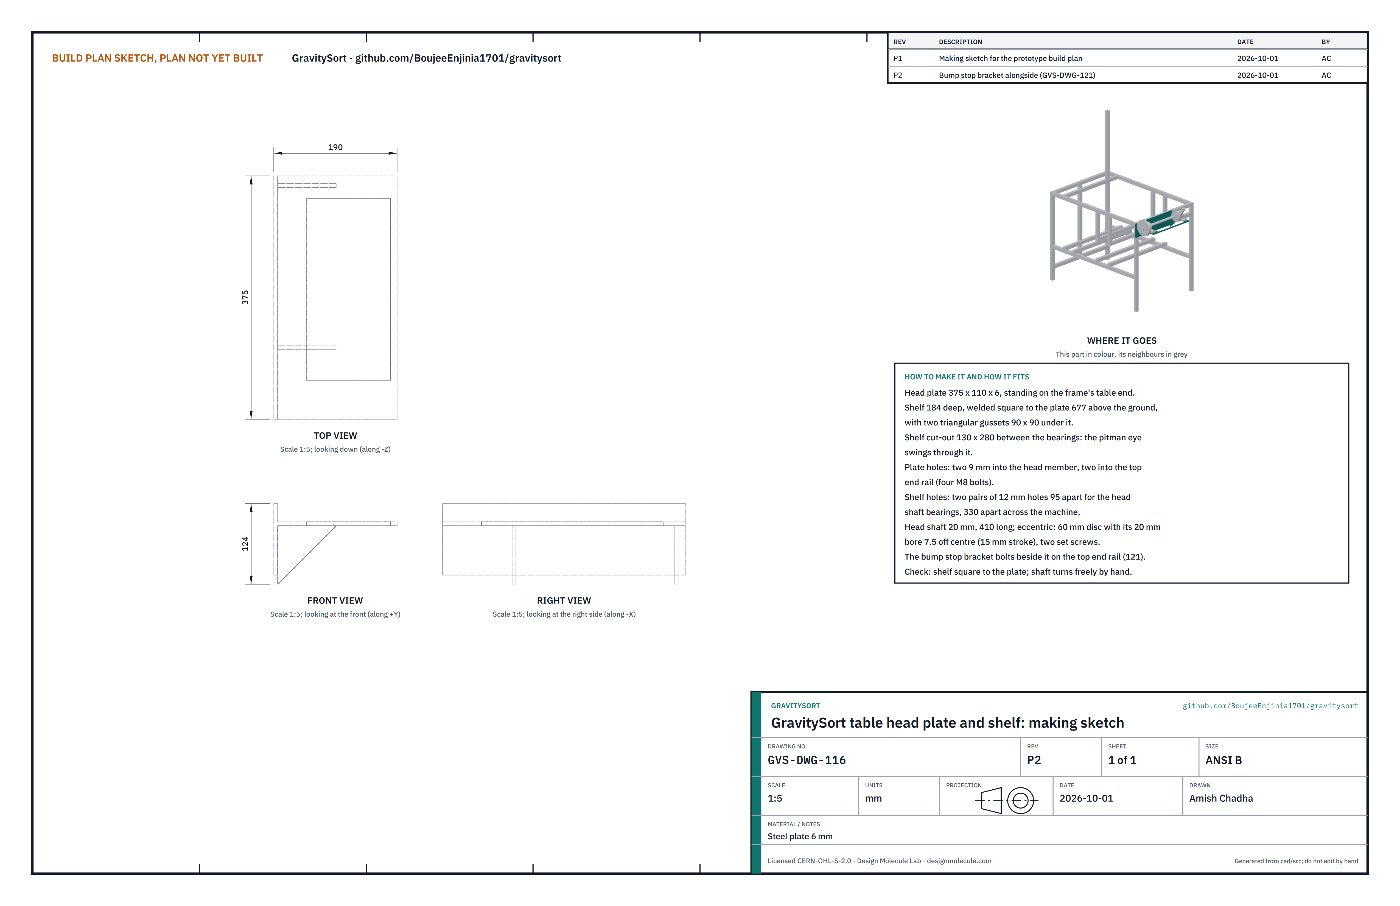
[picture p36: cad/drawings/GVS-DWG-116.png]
Figure 28. Making sketch of the table head plate and shelf


*Figure 28. Table head plate and shelf making sketch (GVS-DWG-116).*

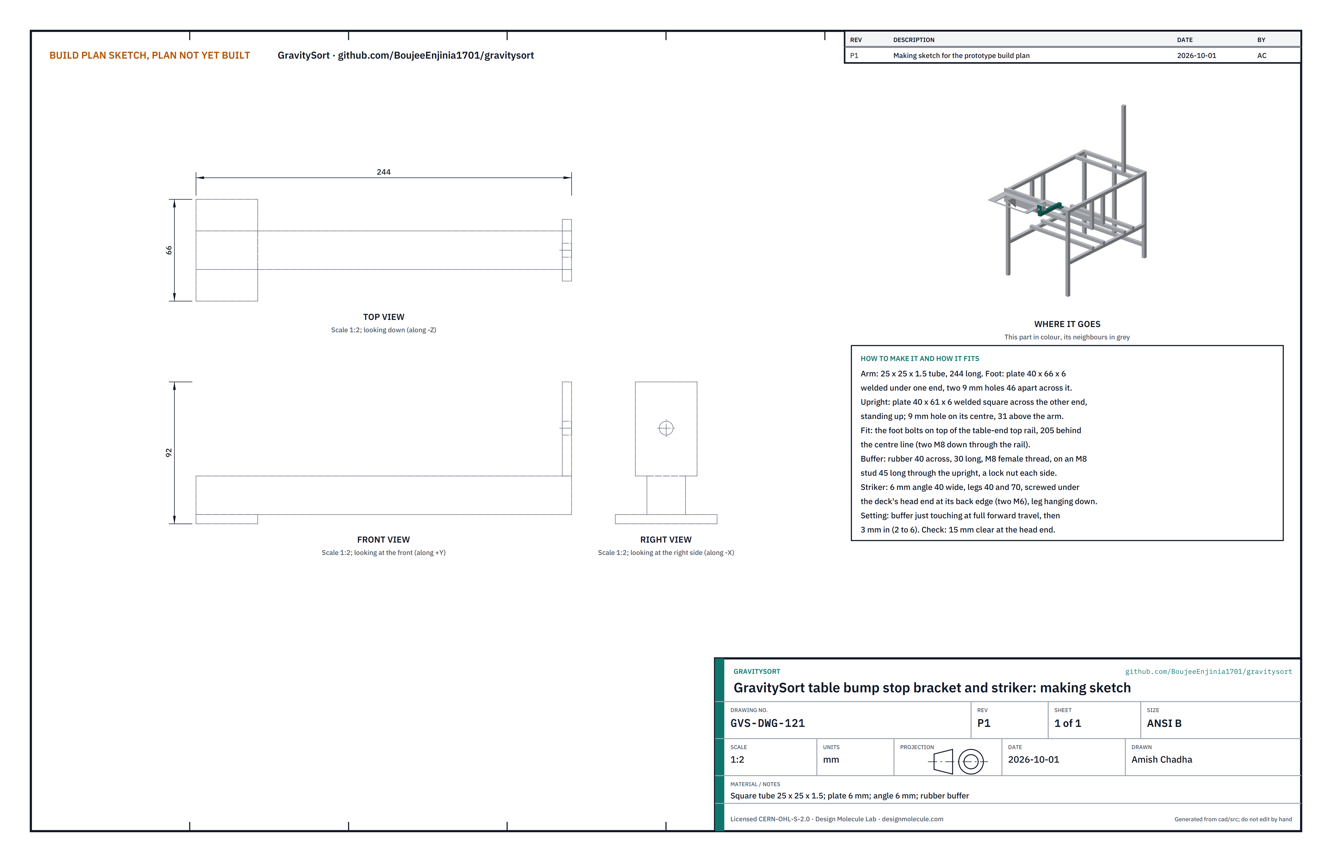
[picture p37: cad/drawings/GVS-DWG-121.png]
Figure 29. Making sketch of the bump stop bracket and striker


*Figure 29. Bump stop bracket and striker making sketch (GVS-DWG-121).*

**What it is and what it is made from.** The bracket on the table end of the frame that carries the head shaft, the eccentric that shakes the deck, and the 125 mm pulley the table belt turns; and, beside it, the bump stop that gives the deck its sharp turn at the far end of each stroke. Steel plate 6 mm; a 20 mm shaft; two 20 mm pillow blocks; a 60 mm eccentric disc. For the bump stop: 25 x 25 x 1.5 mm square tube, 6 mm plate, a short piece of 6 mm steel angle, a bought rubber buffer 40 mm across and 30 mm long (about 55 Shore A, with an M8 thread in its steel back plate, rated for 800 N or more in compression), an M8 stainless threaded rod 45 long and three M8 nuts.

**How to make it.**

1. Cut the head plate 375 x 110 and drill four 9 mm holes to match the head member and the top end rail.
2. Cut the shelf 184 deep, with a cut-out 130 x 280 between the bearing positions; weld it square to the plate, 677 above the ground, with two triangular gussets 90 x 90 under it.
3. Drill two pairs of 12 mm holes in the shelf, 95 apart, for the pillow blocks, 330 apart across the machine.
4. Eccentric: a 60 mm steel disc with its 20 mm bore 7.5 off centre (a 15 mm stroke) and two set screws.
5. Stop bracket: cut the arm 244 long from square tube. Weld a foot plate 40 x 66 under one end, square across it, and drill two 9 mm holes in the foot 46 apart, one each side of the arm. Weld an upright plate 40 x 61 square across the other end, standing up from the top of the arm, and drill a 9 mm hole on its centre line 31 above the arm.
6. Striker: cut 40 mm off a 6 mm steel angle with legs of at least 40 and 70, and drill two 7 mm holes in the short leg for the deck.
7. Bump stop: screw the rubber buffer onto the threaded rod until 10 mm of rod is in it and lock it there with one nut against its back plate. Prime and paint the bracket and striker.

**How it fits the parts next to it.**

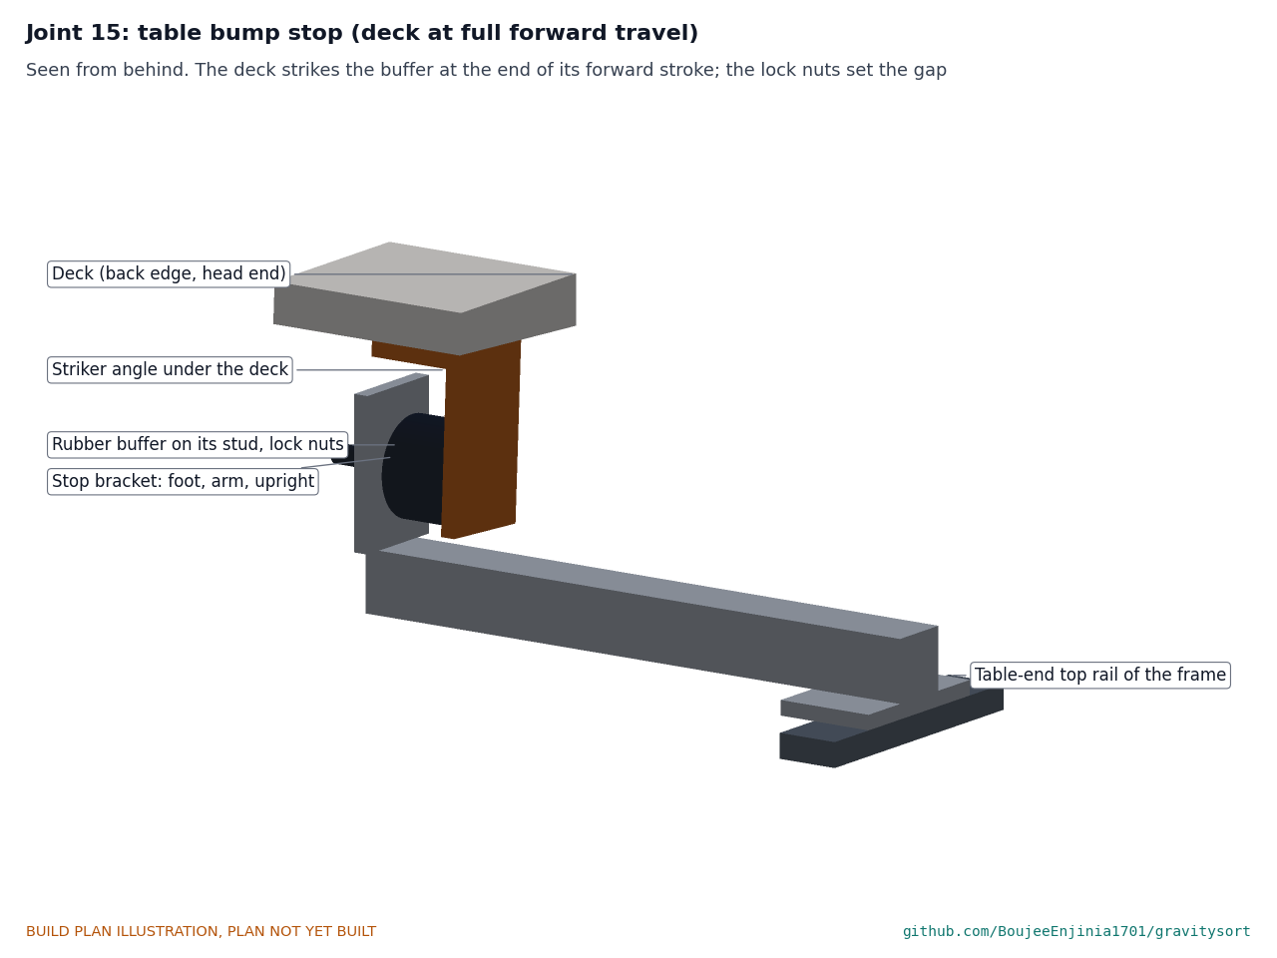
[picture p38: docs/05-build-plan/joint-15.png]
Figure 30. Joint 15: the table bump stop


*Figure 30. Seen from behind. The striker under the deck meets the buffer at the end of the forward stroke; the lock nuts either side of the upright set the gap.*

The head plate bolts to the frame's table end (four M8). The pillow blocks bolt on the shelf; the head shaft runs through them with the eccentric at the centre line and the 125 mm pulley 330 in front of the centre line, in line with the take-off pulley on the jackshaft.

The stop bracket's foot bolts on top of the frame's table-end top rail, 205 behind the centre line (two M8 straight down through the rail), with the arm pointing along the table under the deck's back edge. The buffer's rod passes through the hole in the upright with a lock nut on each side, the buffer facing back toward the frame. The striker's short leg screws flat under the deck at its head end, flush with the head-end edge and the back edge (two M6 bolts through the deck with large washers on top), with its long leg hanging straight down in front of the buffer.

How it works: the pitman pulls the deck toward the head through the near end of its slot; the plywood legs push the deck the other way. On each forward stroke the deck runs on until the striker hits the buffer, and stops there sharply while the pin runs on into the slot and comes back for it. The sharp stop is what walks the gold along the riffles to the concentrate box.

How to set it, with the table belt slack (tensioner handle up) and the head turned by hand:

1. Back the buffer right off. Turn the head shaft until the deck is as far from the frame as it goes, with the pin at the near end of its slot.
2. Move the two lock nuts until the buffer just touches the striker; this is the zero setting. Then turn the buffer 3 mm toward the deck (about two and a half turns of the nuts) and lock both nuts against the upright with a 13 mm spanner. Settings from 2 to 6 mm in are useful; the slot allows up to 8.
3. Take the pitman pin out. Slide the table base away from the frame until the legs lean about 5 mm toward the head at the top when the striker rests on the buffer; the deck then presses on the buffer with about 200 N. Refit the pin.

The nuts are reached from behind the machine, under the deck's back edge, with the deck at rest on the buffer.

**Check before moving on.** The shelf is square to the plate; the shaft turns freely by hand; the head pulley lines up with the take-off pulley (straight edge across both faces). Turning the head by hand, the deck stops on the buffer at the set gap each turn, the pin stays at the near end of its slot until then, and the striker clears the buffer by 15 mm or more at the head end of the stroke. Nothing else touches the striker or the stop bracket.

> **Safety:** The striker and buffer close with up to about 600 N at every stroke. Never put fingers between them, and set the stop only with the table belt slack and the head turned by hand.

### 3.17 Pitman arm

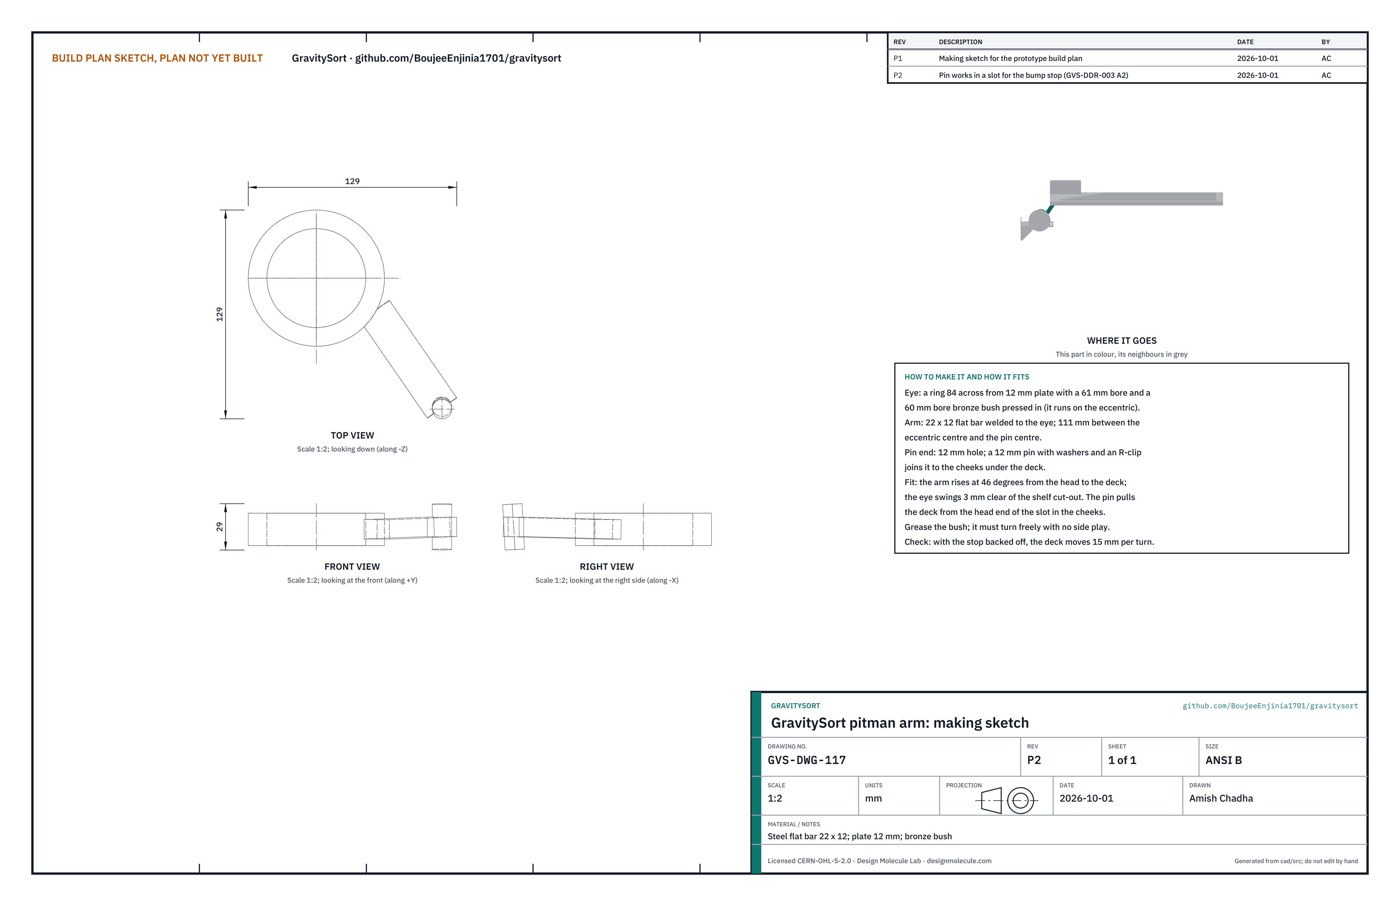
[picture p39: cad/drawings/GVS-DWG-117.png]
Figure 31. Making sketch of the pitman arm


*Figure 31. Pitman arm making sketch (GVS-DWG-117).*

**What it is and what it is made from.** The link that turns the eccentric's rotation into the deck's to-and-fro stroke. Flat bar 22 x 12 mm, 12 mm plate, a 60 mm bore bronze bush and a 12 mm pin.

**How to make it.**

1. Cut a ring 84 across from 12 mm plate with a 61 mm bore; press the bronze bush in.
2. Weld the flat bar arm to the ring so the pin hole is 111 from the eccentric centre; drill the pin hole 12 mm.

**How it fits the parts next to it.**

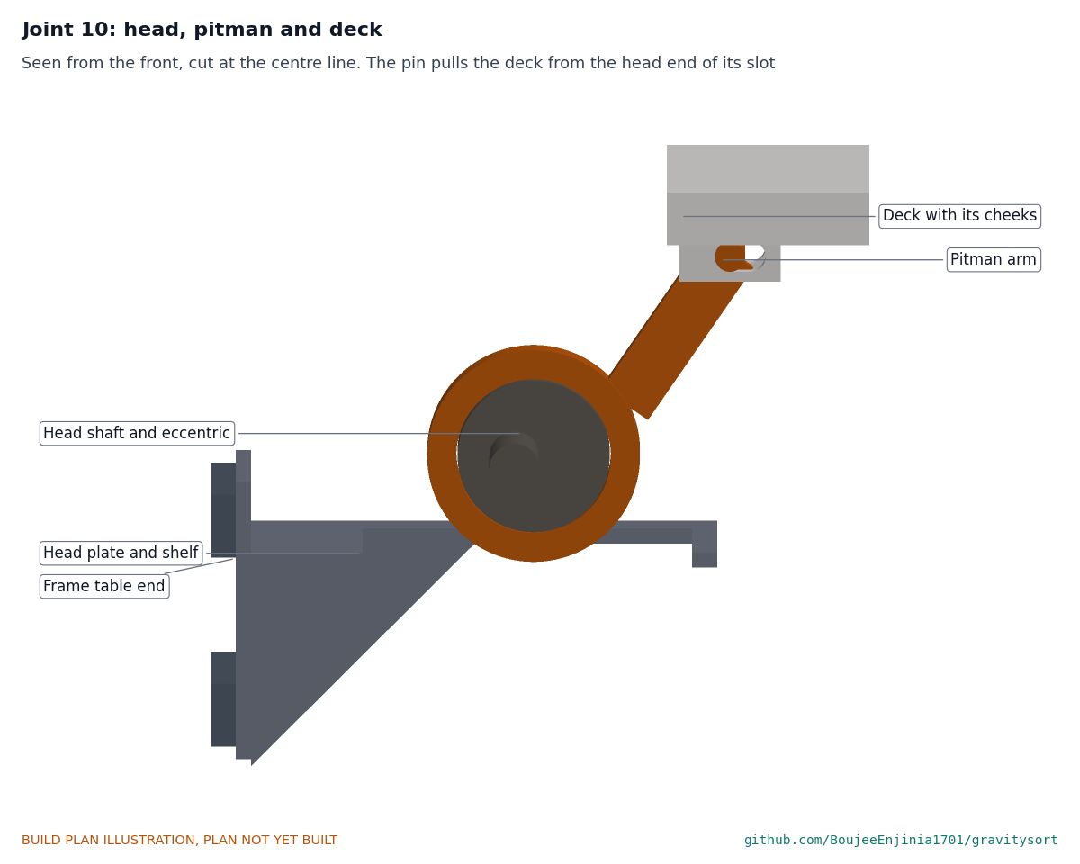
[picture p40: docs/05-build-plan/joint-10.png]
Figure 32. Joint 10: head, pitman and deck


*Figure 32. The eye runs on the eccentric through the shelf cut-out; the pin joins the arm to the cheeks under the deck and pulls from the near end of their slot.*

**Check before moving on.** With the bump stop backed off, turning the head shaft one full turn moves the deck 15 mm and back; the eye clears the shelf all round.

### 3.18 Tailings launder and concentrate box

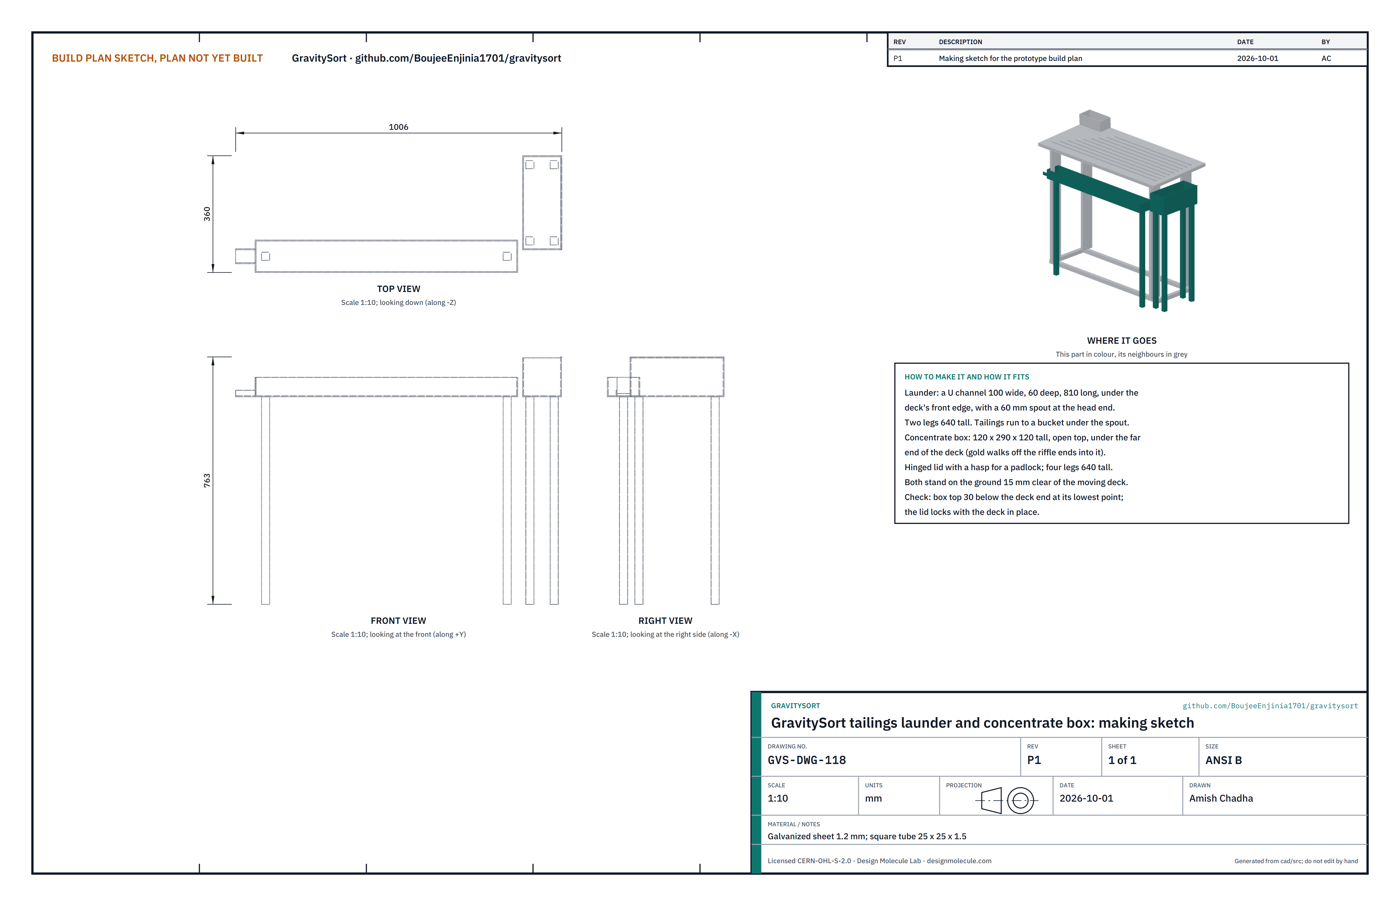
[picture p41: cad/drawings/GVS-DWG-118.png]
Figure 33. Making sketch of the launder and box


*Figure 33. Tailings launder and concentrate box making sketch (GVS-DWG-118).*

**What it is and what it is made from.** The launder catches the light material washed off the deck's front edge; the lockable box catches the gold concentrate that walks off the end of the riffles. Galvanized sheet 1.2 mm and square tube for the legs.

**How to make it.**

1. Launder: fold a U channel 100 wide, 60 deep and 810 long with a 60 mm spout at the head end; weld or rivet two legs 640 tall.
2. Box: fold a box 120 x 290 x 120 tall, open top, with a hinged lid and a padlock hasp; four legs 640 tall.

**How it fits the parts next to it.** The launder stands under the deck's front edge, the box under its far end; both are 15 mm or more clear of the moving deck.

**Check before moving on.** With the deck at both ends of its stroke, nothing touches the launder or the box; the lid locks.

### 3.19 Table belt tensioner and guard

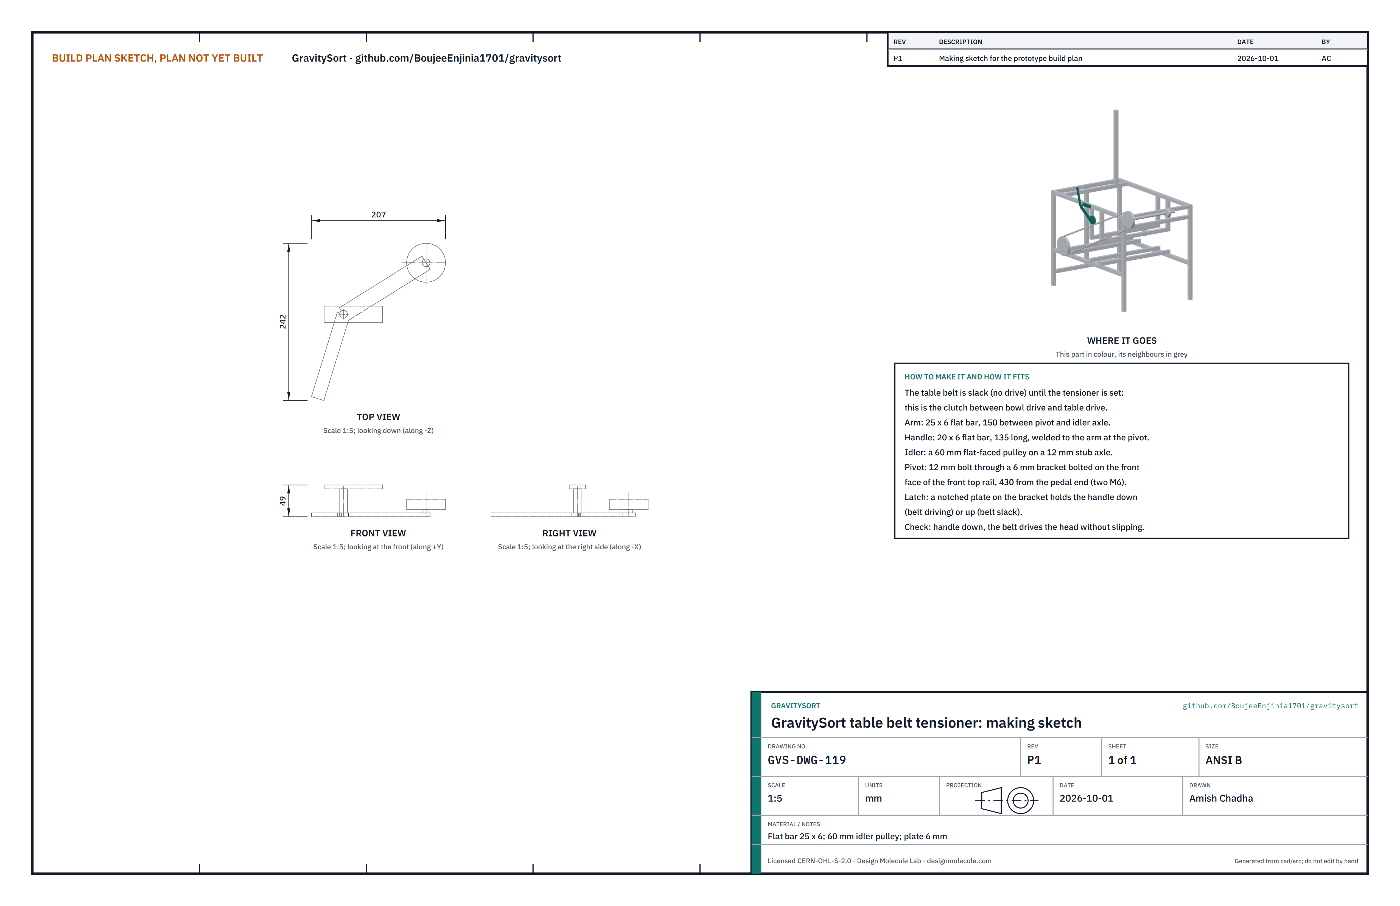
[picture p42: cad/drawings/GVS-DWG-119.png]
Figure 34. Making sketch of the table belt tensioner


*Figure 34. Table belt tensioner making sketch (GVS-DWG-119).*

**What it is and what it is made from.** The table belt runs slack (no drive) until this lever presses an idler onto it, so it is the clutch between bowl and table. Flat bar 25 x 6 and 20 x 6, a 60 mm flat idler pulley, a 12 mm stub axle and pivot bolt, 6 mm plate; the guard is 1.2 mm steel sheet.

**How to make it.**

1. Arm 150 between the pivot hole and the idler axle hole; handle 135 long welded to the arm at the pivot.
2. Bracket: a 6 mm plate with two 7 mm holes for the front top rail, 430 from the pedal end, and a 12 mm pivot hole, and a notched latch plate that holds the handle down (driving) or up (slack).
3. Guard: an outer plate shaped round both table pulleys and the idler, 22 mm outside them, with a 40 mm rim toward the frame and a slot for the arm and handle.

**How it fits the parts next to it.**

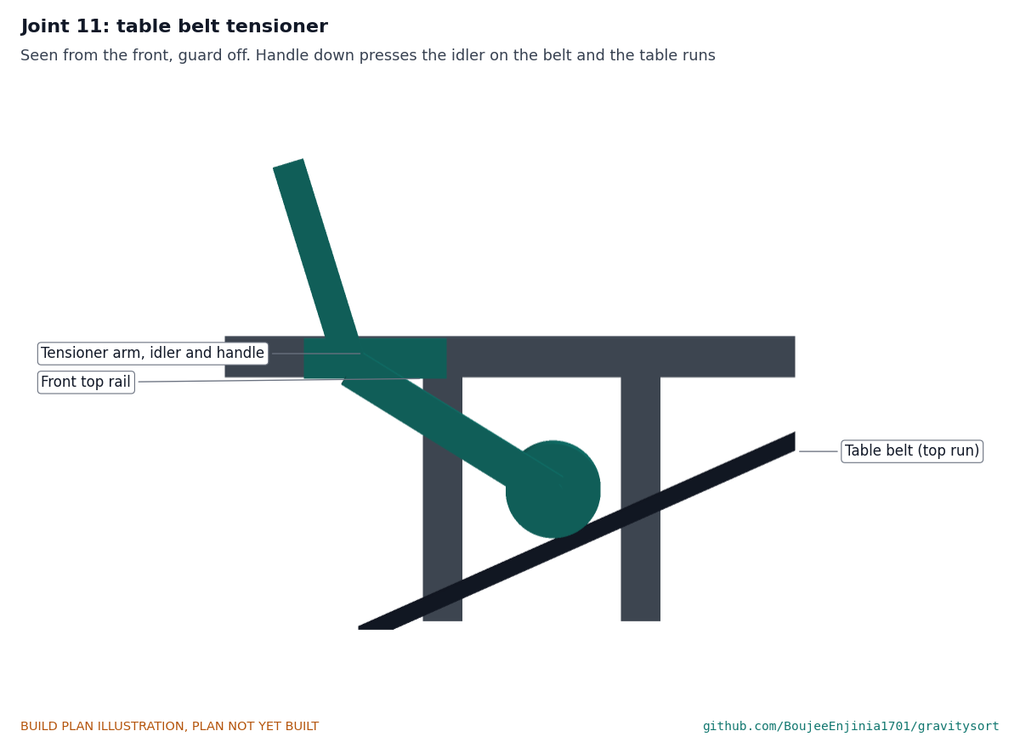
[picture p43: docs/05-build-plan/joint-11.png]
Figure 35. Joint 11: the tensioner on the table belt


*Figure 35. Handle down presses the idler onto the belt's top run and the table runs; handle up and the belt goes slack.*

**Check before moving on.** Handle down, the head turns with the jackshaft without the belt slipping; handle up, the jackshaft turns and the head stays still.

### 3.20 Motor cradle (motor option)

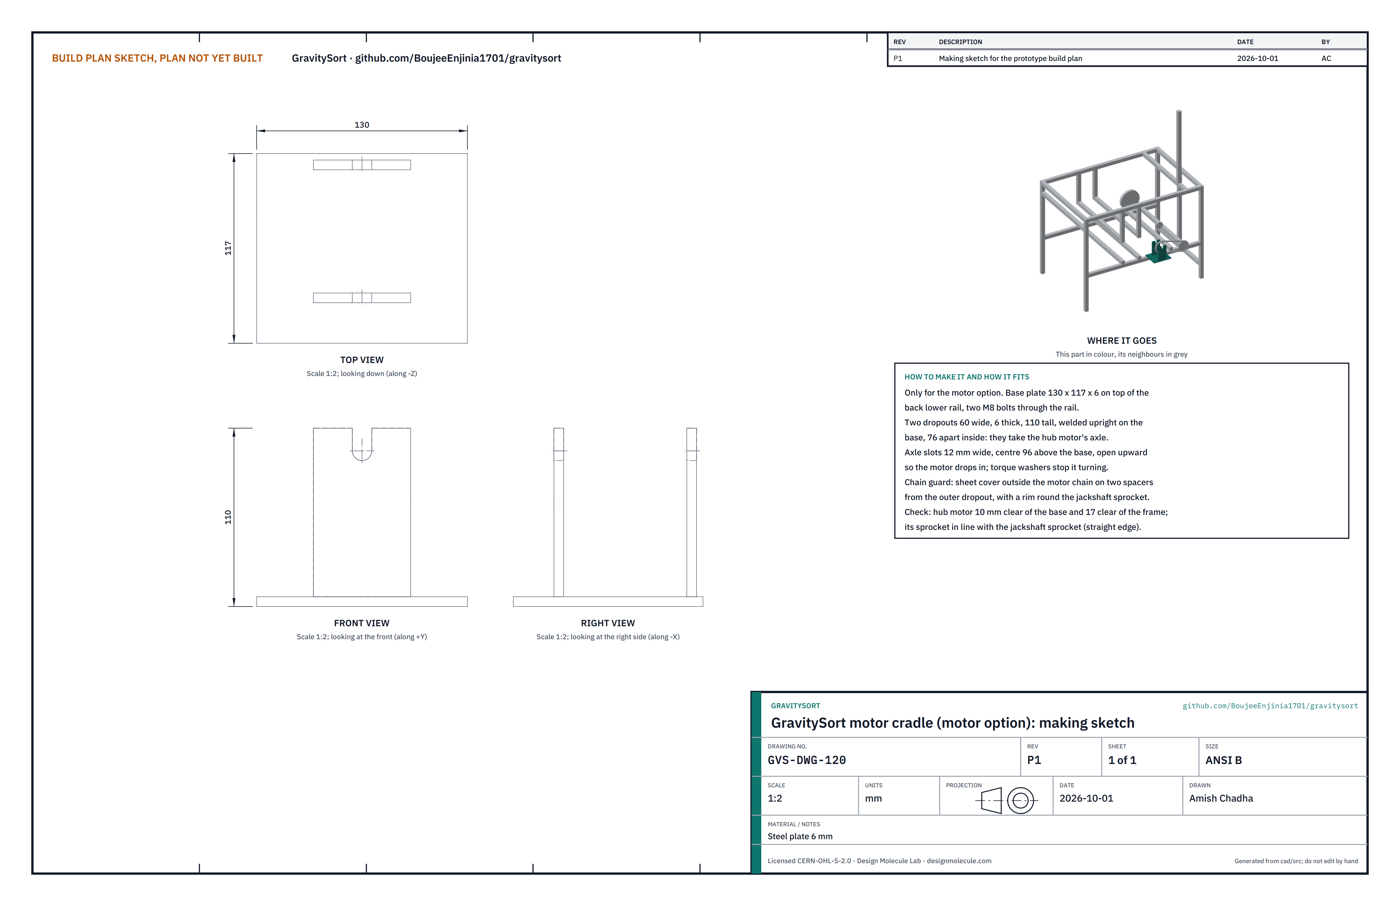
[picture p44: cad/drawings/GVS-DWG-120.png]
Figure 36. Making sketch of the motor cradle


*Figure 36. Motor cradle making sketch (GVS-DWG-120).*

**What it is and what it is made from.** Only for the motor option: the bracket that holds the MotionCore reference hub motor behind the frame. Steel plate 6 mm; a sheet steel chain guard.

**How to make it.**

1. Cut a base plate 130 x 117 and drill two 9 mm holes for the back lower rail.
2. Cut two dropouts 60 wide and 110 tall with a 12 mm slot open upward, centre 96 above the base; weld them upright on the base, 76 apart inside.
3. Make the chain guard: an outer plate round both sprockets with a rim round the jackshaft sprocket, on two spacers from the outer dropout.

**How it fits the parts next to it.**

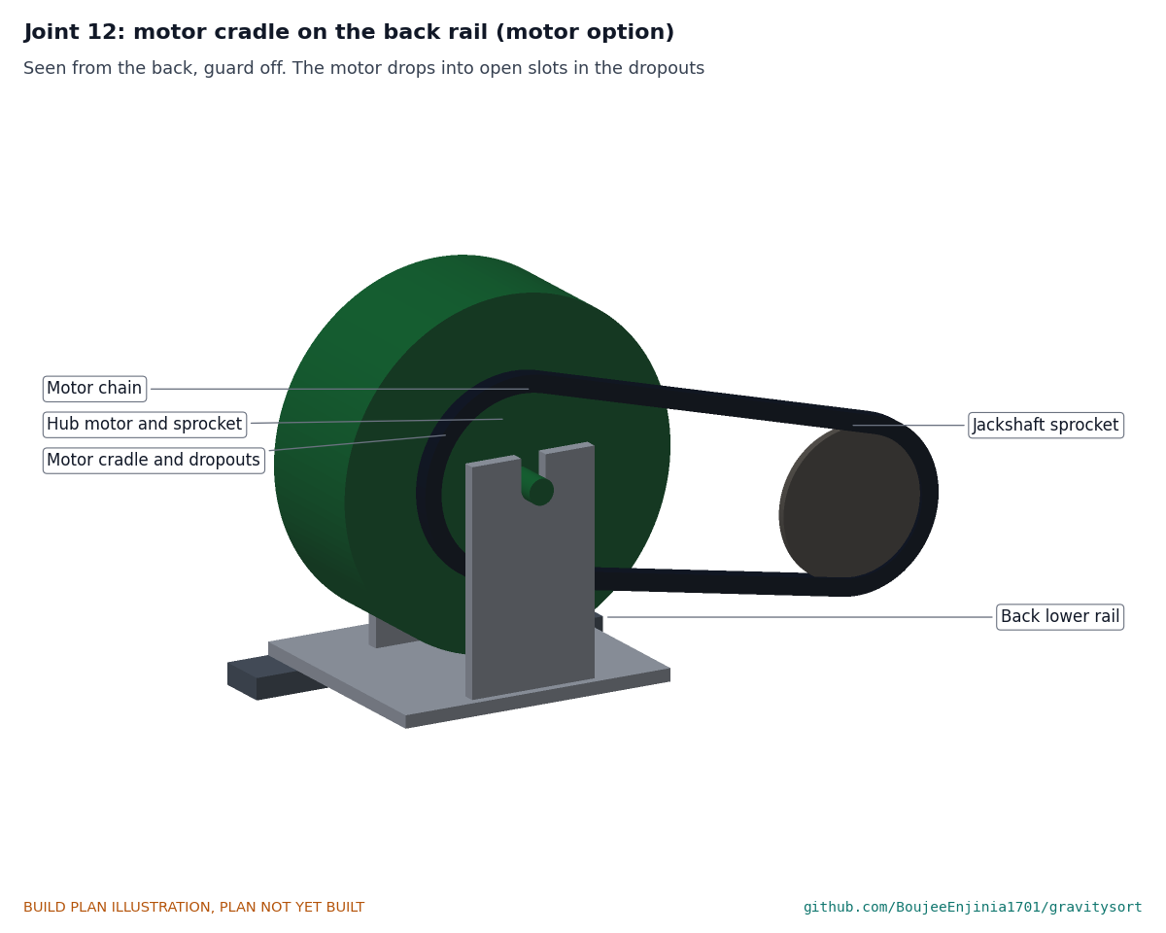
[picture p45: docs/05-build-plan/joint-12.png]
Figure 37. Joint 12: motor cradle on the back rail


*Figure 37. The cradle bolts on the back lower rail; the motor drops into the open slots and its torque washers stop it turning.*

**Check before moving on.** The motor sprocket lines up with the jackshaft sprocket (straight edge); the motor is 10 mm clear of the base and 17 mm clear of the frame.

### 3.21 Bought components

Buy to specification, not brand. Line numbers are those of the bill of materials.

- **Flanged bearing units (line 5).** Two 25 mm bore insert bearings in square flanged housings (UCF205 class), set-screw locking, contact seals.
- **Driven pulley (line 5).** 100 mm A-section V-pulley with a taper bush for 25 mm.
- **Rotary union (line 4).** Single-passage water rotary union, 1/2 in BSP on the shaft side, side port for a 3/4 in hose tail.
- **Shaft flange hub (line 4).** 25 mm bore, about 80 mm flange with four holes on a 60 mm circle.
- **Gearbox (line 9).** Right-angle 1:1 bevel gearbox with a through 20 mm input shaft about 33 mm above its feet and a downward output shaft; a used agricultural or garden machine gearbox is fine.
- **Jackshaft parts (line 9).** 20 mm bright steel shaft 740 long; two 20 mm pillow blocks (UCP204 class); a 12T bicycle freewheel on an adapter; a 140 mm A-section take-off pulley; the 300 mm A-section drive pulley for the gearbox output; the motor sprocket if the motor is fitted.
- **Belts and chain (lines 9 and 10).** An A-section link V-belt for the bowl drive (fixed centres, so the length is set by its links); an A-section V-belt to length for the table drive (measure on the machine); 1/2 x 1/8 in bicycle chain.
- **Bicycle parts (line 8).** Bottom bracket shell (cut from a scrap frame), bottom bracket bearings and axle, crank arms with a 48T chainring, pedals, saddle, 27.2 mm seat post and seat clamp.
- **Brake (line 18).** 160 mm 6-bolt disc, mechanical disc caliper, brake lever with a parking latch, cable and housing; a pin on the cable for the lid clamp.
- **Speed display (line 19).** Wired bicycle computer with its magnet and sensor.
- **Water (line 13).** 60 L HDPE drum, 3/4 in ball valve and tank connector, 2 to 20 L/min rotameter, 3/4 in hose and clips, a ratchet strap, a tee, valve and hose to the wash pipe.
- **Tub fittings (line 6).** Rubber pipe grommets for 63 and 75 mm pipe in a 6 mm wall; 63 and 75 mm pipe offcuts.
- **Bump stop buffer (line 22).** A cylindrical rubber-metal buffer 40 mm across and 30 mm long, natural rubber about 55 Shore A, steel back plate with an M8 female thread, rated for 800 N or more in compression; an M8 stainless threaded rod 45 long and three M8 nuts.
- **Fixings (line 17).** M6, M8 and M10 bolts with nylon-insert nuts and washers (about 60 in all), six M6 x 4 stainless nuts for the liner, a 6 mm pin and R-clip for the hub and a 12 mm pin for the pitman, hose clamps, sealant, an O-ring for the jacket floor, primer and paint.
- **Motor option (lines 12 and 20).** The MotionCore kit and its reference 250 W geared hub motor with a sprocket on its disc mount (from the MotionCore project), and a battery the user chooses.
- **Flush container (line 23).** A 10 L HDPE pail with a push-on lid, about 250 mm across and 280 mm tall, and a steel hasp and staple about 36 x 100 mm. Rivet the staple to the pail wall, about 200 mm up at the front, and the hasp strap to the lid so that it drops over the staple; use four rivets each with backing washers inside. The padlocks come from the partner, two if the crew opens it with two people.

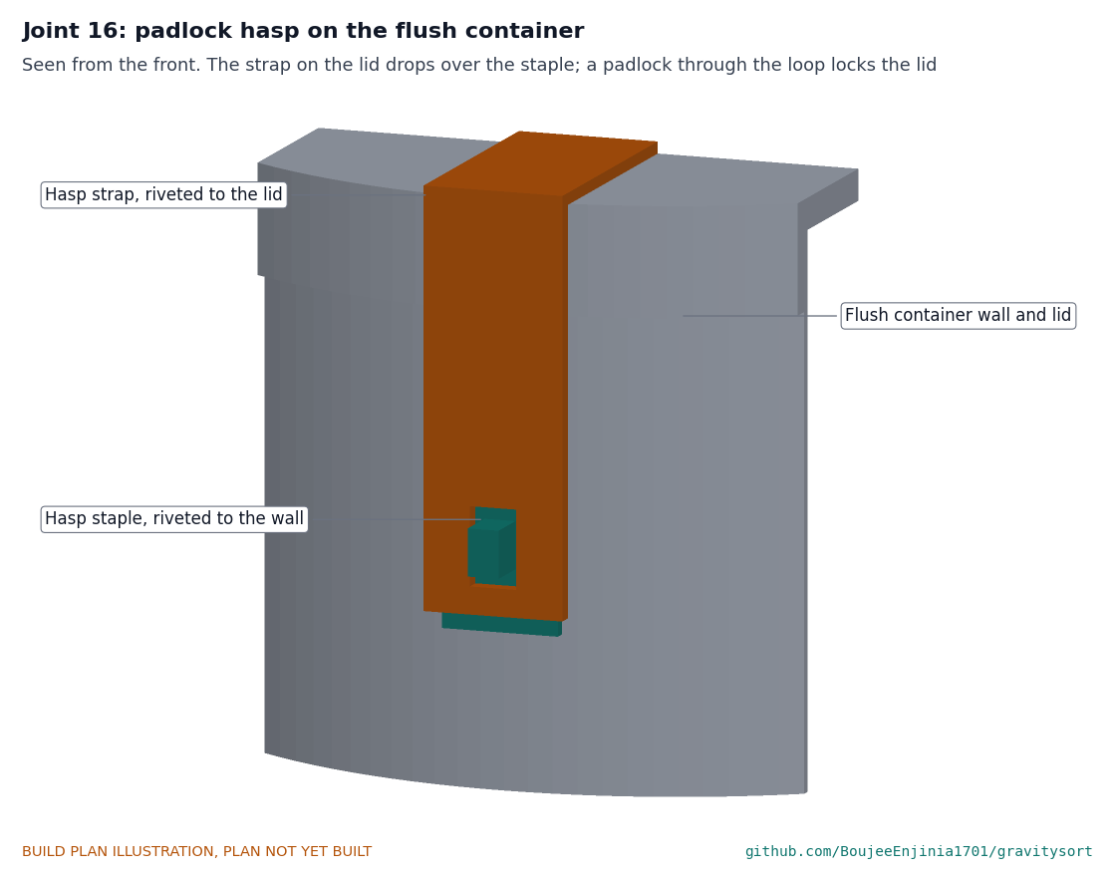
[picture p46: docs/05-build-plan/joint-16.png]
Figure 38. Joint 16: padlock hasp on the flush container


*Figure 38. The strap riveted on the lid drops over the staple riveted on the wall; a padlock through the staple's loop keeps the lid shut. The container stands loose on the ground in front of the tub, where the rings are rinsed into it.*

## 4. Putting it together

In each picture the parts already fitted are grey and the parts being fitted are in colour, with an arrow showing the way they go in.

### Step 1: set the frame on level ground

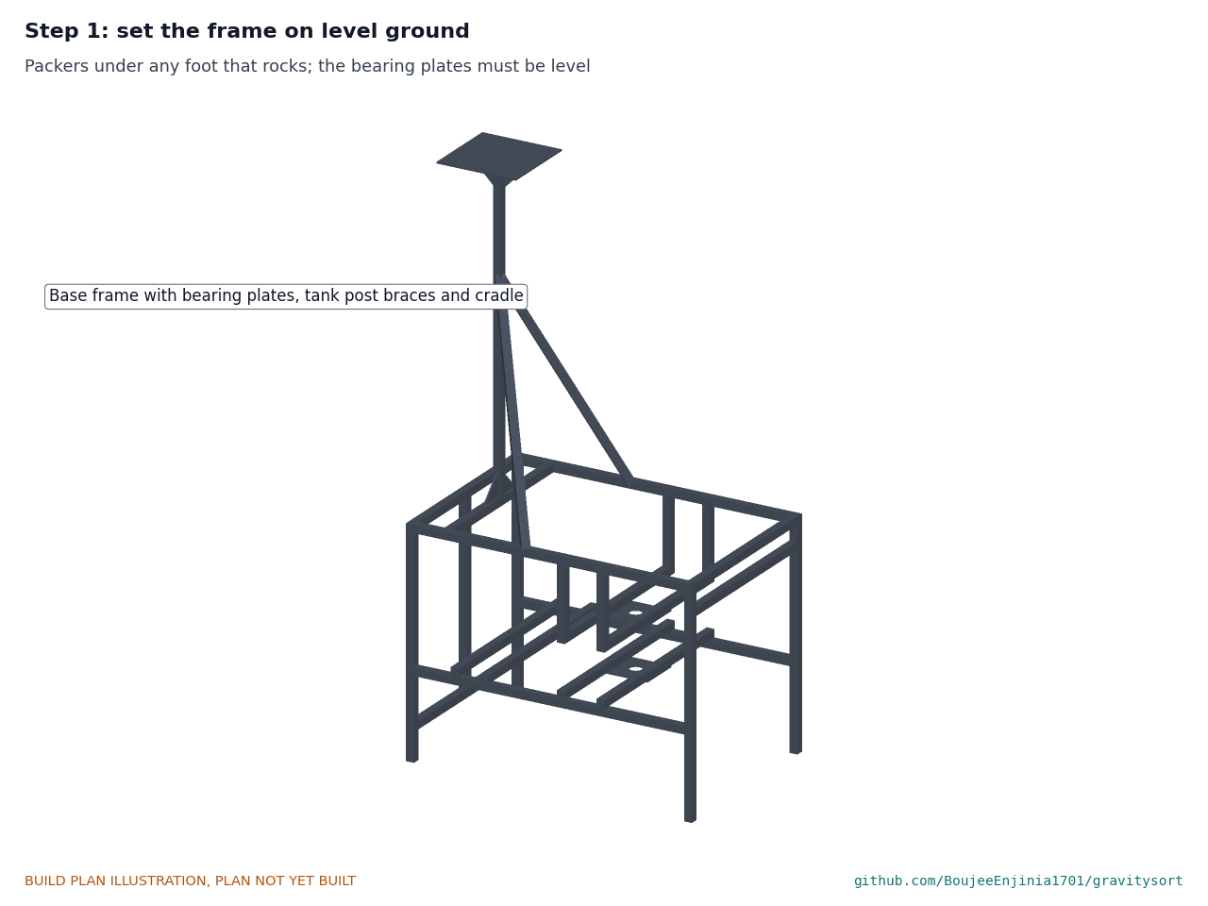
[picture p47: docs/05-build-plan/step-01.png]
Step 1


Put a packer under any foot that rocks. Check the bearing plates are level with a spirit level.

### Step 2: bolt the pedal outrigger to the frame end

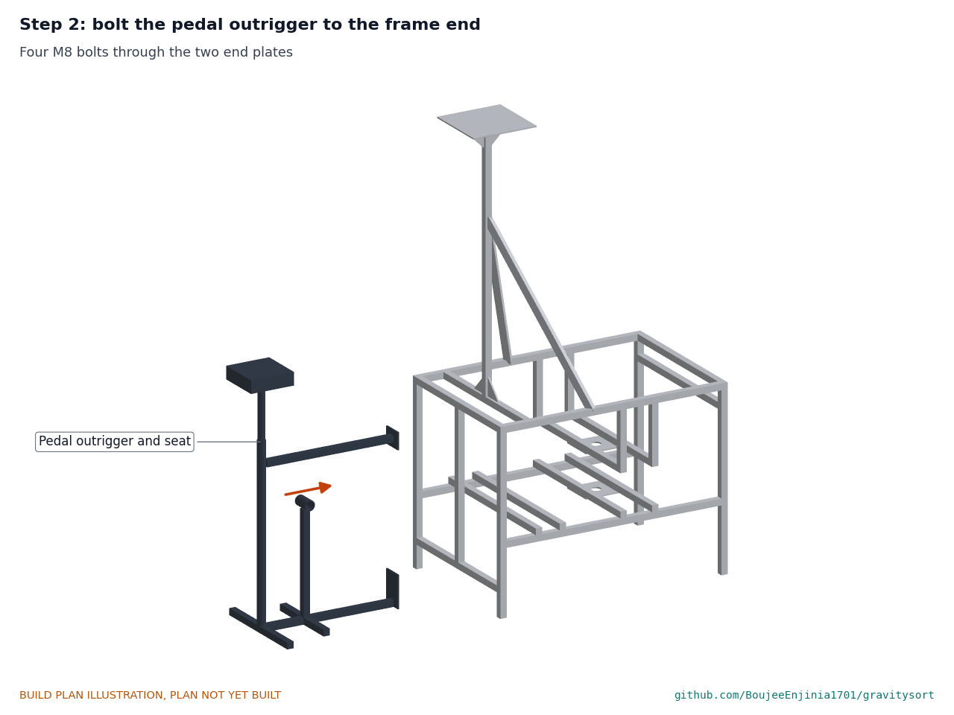
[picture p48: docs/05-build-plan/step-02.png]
Step 2


Four M8 bolts through the two end plates, with washers and nylon-insert nuts.

### Step 3: gearbox, jackshaft and drive pulley

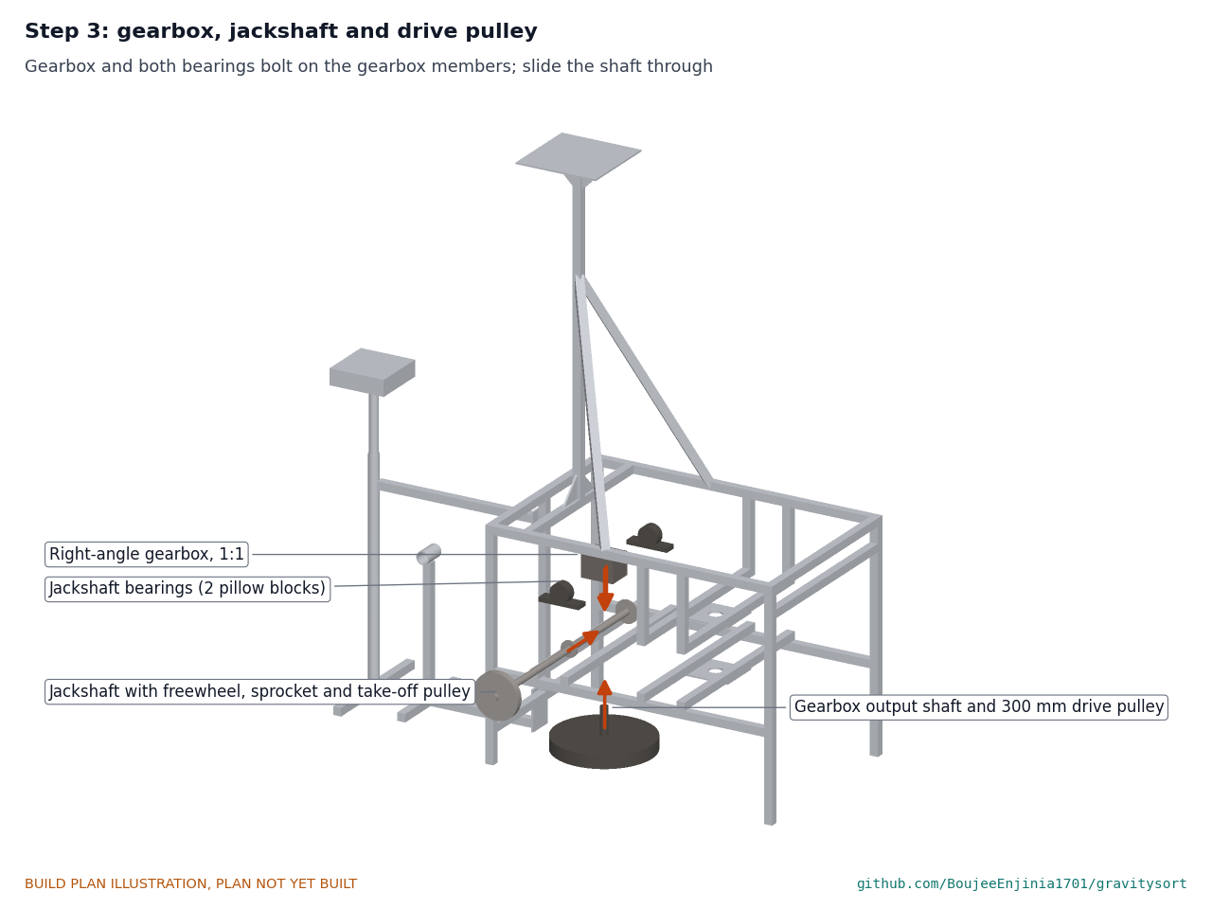
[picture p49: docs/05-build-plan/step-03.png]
Step 3


Bolt the gearbox across the two gearbox members (four M8). Slide the jackshaft through the front pillow block, the gearbox's input, the freewheel and the back pillow block, with the take-off pulley on its front end and the motor sprocket (if fitted) on its back end; bolt the pillow blocks down (four M10 each pair). Fit the 300 mm drive pulley on the gearbox output shaft under the members.

### Step 4: crankset and pedal chain

Step 4

Fit the bottom bracket bearings and axle, the cranks and the 48T chainring. Fit the chain round the chainring and the freewheel and set its slack to about 10 mm at the middle of the lower run.

### Step 5: bearings, spindle, brake disc and driven pulley

Step 5

Bolt the two bearing units under their plates (four M10 each), loosely. Feed the spindle down through the upper bearing, the brake flange (with the disc bolted on), the lower bearing and the driven pulley. Set the spindle so its top is 536 above the ground, tighten the bearing bolts, then the set screws on the flats; clamp the brake collar and the pulley's taper bush. **Hold point:** the spindle turns freely by hand and the disc runs true.

### Step 6: rotary union and bowl belt

Step 6

Seen from below. Screw the rotary union onto the nipple at the spindle foot with thread sealant, its side port toward the pedal end. The bowl belt is a link V-belt, because the pulley centres are fixed: fit it round both pulleys and add or remove links until it deflects about 10 mm under a firm thumb.

### Step 7: belt guard and chain case

Step 7

Seen from below. Bolt the belt guard on its four hangers and fit its tray. Fit the chain case: flat on the left gearbox member (one M6) and tabbed to the pedal post (one M6), then its outer plate.

### Step 8: brake caliper, lever and speed display

Step 8

Bolt the caliper bracket on the right spindle member (two M6) and the caliper on it. Fix the brake lever and the speed display to the pedal-end top rail, facing the rider; run the brake cable to the caliper and the interlock pin's branch to the right lid clamp; run the sensor wire from under the guard to the display. Set the display's wheel size to 1,667 mm.

### Step 9: splash tub, standpipe and tailings pipe

Step 9

Set the tub on the tub members and bolt it down (four M8 with large washers). Push the standpipe through its grommet until it stands on the upper bearing plate. Fit the tailings pipe through its grommet at the back and connect the hose to the settling pond.

### Step 10: bowl onto the spindle

Step 10

Lower the bowl, jacket and hub together over the spindle top until the hub flange sits on the spindle's stop, line up the cross holes, and push the 6 mm pin through with its clip. **Hold point:** the bowl spins true by hand, at least 12 mm clear of the standpipe and 50 mm clear of the tub wall.

### Step 11: lid guard and clamps

Step 11

Fit the lid on the rim and close both clamps. Fit the interlock pin to the right clamp.

### Step 12: hopper support, hopper and screen

Step 12

Bolt the support foot on the front top rail (two M8). Drop the hopper into its ring and lay the screen on top. Check the pipe end is 15 mm above the lid.

### Step 13: header tank, valve, rotameter and hose

Step 13

Joint 8: header tank on its braced post

Fit the tank connector and valve near the bottom of the drum, on its back. With a helper and a stepladder, lift the empty drum onto the cradle, 1.7 m up, and strap it to the post; never lift it with water in it. Bolt the rotameter bracket on the back top rail. Run the 3/4 in hose from the valve straight down inside the frame, then back over the rotameter bracket into the top of the rotameter, then down outside the back of the frame, along the ground under the belt guard, to the rotary union's side port. Clip it every 300 mm.

### Step 14: table base and flexure legs

Step 14

Set the base on level ground, in line with the frame, with its head end about 190 from the frame's table end; its final position is set with the bump stop in step 16. Bolt the four legs to the base rails with their bottom cleats.

### Step 15: deck onto the legs

Step 15

With a helper, lay the deck on the leg tops and bolt the top cleats to its underside. Set the slope to 3 degrees down to the front with packers under the back cleats.

### Step 16: table head, pitman and bump stop

Step 16

Bolt the head plate to the frame's table end (four M8). Bolt the pillow blocks on the shelf, slide the head shaft through with the eccentric and the pulley, and tighten them. Fit the pitman eye over the eccentric through the shelf cut-out and pin its other end in the slot between the deck cheeks (12 mm pin, washers and an R-clip). Bolt the stop bracket's foot on the table-end top rail behind the head plate (two M8), screw the striker under the deck's head end at its back edge (two M6), and fit the buffer and its rod through the upright with a lock nut each side. Set the stop 3 mm in and the legs' push on the buffer as section 3.16 says. **Hold point:** turning the head by hand, the deck stops on the buffer each turn and nothing else touches.

### Step 17: table belt, tensioner and guard

Step 17

Bolt the tensioner bracket on the front top rail (two M6) and fit the arm and idler. With the handle up, fit the table belt round the take-off and head pulleys. Bolt the table belt guard to the frame and the head plate. **Hold point:** handle down, the table runs; handle up, it stops.

### Step 18: tailings launder and concentrate box

Step 18

Stand the launder under the deck's front edge with its spout at the head end over a bucket, and the box under the deck's far end. Check 15 mm clearance to the deck at both ends of its stroke.

### Step 19: motor option

Step 19

Seen from the back. Only for the motor option: bolt the cradle on the back lower rail (two M8), drop the motor into the dropouts with its torque washers, fit the chain to the jackshaft sprocket and the guard. Hang the MotionCore module under the top rails at the pedal end on two straps, wire it as the MotionCore build plan says, set its speed limit to 900 rpm at the spindle, and wire the lid switch to a brake input. **Hold point:** safety stop S6 in section 6.

## 5. First checks

These are the checks a TRL 4 test report would record; this plan only lists them. Requirement numbers are those of GVS-REQ-001.

*Table 2. First checks.*

| Check | Requirement | How | Pass when |
| --- | --- | --- | --- |
| Guards fitted | R12 | Try to reach every belt, chain, pulley and sprocket by hand with the drive still | No moving part can be reached |
| Brake and interlock | R12, R13 | Spin the bowl to about 600 rpm (pedals, no water), stop pedalling, pull the brake; try to open the right clamp before and after parking | Stops within 15 s; the clamp opens only with the brake parked |
| Speed display | R3 | Pedal at a steady cadence; count the cadence | The display reads bowl rpm / 10, matching 12 times the cadence within 5 % |
| Pedal speed range | R3, R6 | Pedal at 50, 60 and 71 rpm | 600 to 850 rpm at the bowl |
| Fluidization flow | R4, R8 | Fill the tank, open the valve, read the rotameter with the bowl still and turning at 730 rpm | 8 to 15 L/min; water from every ring groove |
| Water use | R8 | Rotameter plus the slurry water at the feed rate | 1.5 m3/h or less |
| Table drive | R5 | Handle down, pedal at 60 rpm; count the strokes; measure the stroke with the bump stop backed off, then set 3 mm in | 240 to 300 strokes per minute; 15 mm stroke backed off, 12 mm set |
| Table bump stop | R5 | Run the table with concentrate and wash water at settings of 2, 3, 4 and 6 mm | A sharp knock at the far end of every stroke; gold moves along the riffles to the box; the nuts have not moved after 30 min |
| Lid off for a flush | R13 | Time stopping, braking, opening the lid and rinsing the rings into a container | 5 min or less, no tools |
| Loads and mass | R11 | Weigh each of the six loads | Every load 30 kg or less; total recorded (about 99 kg estimated) |
| Header tank on its post | R4, R8 | Fill the tank with the machine level; read the rotameter with the valve open and the tank half full; push sideways on the full tank with a spring balance up to 100 N | 12 L/min or more with the valve open; nothing bends and the machine does not lift off its feet |
| Flush container lock | R13 | Rinse the rings into the flush container, shut the lid and lock the hasp | The lid cannot be lifted with the padlock in |
| Assembly time | R11 | Two people assemble the six loads with hand tools | 30 min or less |

## 6. Safety stops

Stop at each point. Carry on only when everything listed is true.

- **S1. Before any welding.** Fire extinguisher and a clear, non-flammable floor; no solvents, resin or plastic nearby; helmet, gloves and covered skin.
- **S2. Before laminating or casting.** Ventilation running; gloves, eye protection and an organic vapour respirator; resin and polyurethane datasheets read; no flame or welding in the same space.
- **S3. Before the bowl turns for the first time (step 10).** The liner has no cracks, voids or debonding; all four bowl bolts and the hub pin are in; the bowl spins true by hand; the lid, clamps, belt guard and chain case are fitted.
- **S4. Before any spin above hand speed.** The brake stops the bowl and parks; the interlock pin stops the right clamp opening; the speed display works; nobody stands in line with the tub; a calculation shows that the tub and lid contain a piece of liner thrown at 1,200 rpm.
- **S5. Every run.** Never above 900 rpm (90 on the display). Before opening the lid: stop pedalling, apply and park the brake, and wait for the bowl to stop. Never remove or bypass the interlock pin.
- **S6. Before the motor is powered (motor option).** The MotionCore emergency stop works and is within the operator's reach; its speed limit is set to 900 rpm at the spindle and checked; the lid switch removes torque; the battery is out of the wet.
- **S7. Before the table runs.** The table belt guard is on; the bump stop's lock nuts are tight; nobody's hands are near the striker and buffer. Set or adjust the stop only with the tensioner handle up and the head turned by hand.
- **S8. Before water and slurry.** The settling pond is fenced; boots with grip; no mercury anywhere on site. The machine stands level before the header tank is filled; nobody climbs on the frame or hangs anything on the tank, because about 190 N pushed sideways at a full tank tips the machine.

## 7. Tools, skills and workspace

**Tools.** Angle grinder with cutting and flap discs, or a metal bandsaw; MIG or stick welder; bench drill and hand drill with drills 3 to 12 mm, a 40 mm hole saw and step drill, and 76 and 98 mm hole saws for plastic; taps M5 and M6; files, deburring tool, square, tape, scriber, spirit level, plumb line and callipers; jigsaw with wood, plastic and metal blades; sheet snips, a folder or bending bar for 1.2 mm sheet, and a rivet tool; TIG welder (or a fabricator) for the stainless nipple; FDM 3D printer for the plugs and the core; laminating brushes, rollers and mixing gear; spanners and sockets to 17 mm; torque wrench; tachometer or the speed display; stopwatch; scale to 30 kg.

**Skills.** Welding steel tube to a square, accurate frame; glass fibre lay-up and polyurethane casting; drive alignment of belts and chains. No certified trade is needed, but the welds that carry the spindle and the gearbox should be made by someone who welds regularly.

**Workspace.** A flat concrete floor about 4 x 3 m for the frame and table; a separate ventilated area for laminating and casting; a fire-safe area for welding and grinding; outdoor space with water for the first runs.

**Personal protective equipment.** Welding helmet and gloves; safety glasses; hearing protection for grinding; nitrile gloves and an organic vapour respirator for resin work; cut-resistant gloves for sheet metal; boots with grip near water.

## 8. Where the numbers come from

- Model and constructability checks: `cad/src/model.py` (`python cad/src/model.py --check`, 126 checks); STEP and STL exports in `cad/step/` and `cad/stl/`.
- Pictures: `cad/src/build_plan_media.py`, using `.kit/build_views.py`; written to `docs/05-build-plan/` and `cad/drawings/GVS-DWG-101` to `GVS-DWG-121`.
- General arrangement: `cad/drawings/GVS-DWG-001.pdf`, Rev P5.
- Calculations: `docs/04-calcs/01-sizing.md` (GVS-CAL-001 v0.8) and `docs/04-calcs/sizing.py`; water pressure from the tank in section 6, bump stop in section 9, spindle in section 10, mass, loads, tank post and tipping in section 11, cost in section 12.
- Bill of materials: `bom/bom.csv` and `bom/bom-notes.md`.
- Decisions: `docs/decisions/0003-design-for-construction.md` (GVS-DDR-003), with GVS-DDR-001 and GVS-DDR-002; open decisions in `docs/06-design-decisions.md` (GVS-DEC-001).
- Requirements: `docs/03-requirements.md` (GVS-REQ-001 v1.0).

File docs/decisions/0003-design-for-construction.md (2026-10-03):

---
doc_id: GVS-DDR-003
title: GravitySort design for construction
project: GravitySort
doc_type: Design decision record
version: "0.5"
status: Draft
date: '2026-10-02'
author: Amish Chadha
license: CERN-OHL-S-2.0
revisions:
- version: "0.1"
  date: '2026-10-01'
  author: Amish Chadha
  change: Changes that make the concept physically buildable, with the reason for each; made under Amish's 2026-09-30 instruction to make the design physically buildable; open for his review
- version: "0.2"
  date: '2026-10-01'
  author: Amish Chadha
  change: Accepted by Amish, including the recommendations for A1 to A3
- version: "0.3"
  date: '2026-10-01'
  author: Amish Chadha
  change: A2 carried out; the table bump stop is now in the model, BOM, calculations, making sketch GVS-DWG-121 and build plan (section 3.16, step 16); the pitman pin works in a slot so the deck can strike the stop
- version: "0.4"
  date: '2026-10-01'
  author: Amish Chadha
  change: Accepted by Amish, the change made while adding the bump stop (slotted pitman pin with 8 mm free play in the deck cheeks; plywood legs set leaning about 5 mm to press the deck on the buffer with about 200 N), Table 2; no design change
- version: "0.5"
  date: '2026-10-02'
  author: Amish Chadha
  change: "Decisions of 2026-10-02 (GVS-DEC-001) carried into the constructable design: tank post 1.7 m on the centre line with two braces; flush container with a padlock hasp (BOM item 23); appearance model rebuilt from the model; 126 checks"
---

# 0003: Design for construction

- **Date:** 2026-10-01
- **Status:** accepted. Amish, 2026-10-01: "i agree with your recommendations for both GrowRider and GravitySort". This covers every change in Tables 1 and 2 and the recommendations in Table 3 (A1 to A3), which are now decided as recommended and recorded in the design decisions register (GVS-DEC-001). The change made while carrying out A2 (the slotted pitman pin and the leaning legs, Table 2, "Table bump stop"), which was open for his review, was accepted the same day. Amish, 2026-10-01: "I approve of your recommendations for PicoFlow and GravitySort".

## Context

On 2026-09-30 Amish asked for every repo to have an illustrated prototype build plan and wrote: "If you are realising that the design cannot be built as per concept - fix the design assumptions to match and be physically feasible as you draw the illustrations." The TRL 3 model of GVS-DDR-002 showed what GravitySort does, but it was a massing model: several cross members floated in mid-air, two shafts passed straight through the members meant to carry them, the bearings had nothing to bolt to, the spindle had no way to carry water to the jacket, the lid could not be lifted off past the feed pipe, the table belt looped round a frame rail, and the hose to the rotary union ran through the drive pulley. Checking the model with build123d (intersections, contacts and clearances between every pair of parts) found each of these.

The changes below keep what GravitySort does: the same two stages, the same bowl, riffle rings, jacket and 12:1 drive, the same brake and lid interlock, the same table, tank and motor option, at the same main positions. `cad/src/model.py` now models every component as it is made or bought and runs 102 constructability checks (`python cad/src/model.py --check`): parts that must touch do touch, parts that must run clear are clear by at least the stated gap. All 102 pass.

## Decision

*Table 1. Changes made to the model, the BOM and the calculations.*

| # | Problem in the concept | Change made | Why this way |
| --- | --- | --- | --- |
| P1 | The tub cross members, the spindle bearing member, the jackshaft member and the motor member sat at heights where no rail joined them, so they floated. The spindle passed through its own bearing member and the gearbox output shaft through the jackshaft member. | The low stretchers move up to become lower side rails (255 to 280 mm). Four 600 mm members lie across on top of them in two pairs, one pair either side of the gearbox output shaft and one pair either side of the spindle. The two tub members (445 to 470 mm) hang from the top side rails on four 205 mm drop posts. A low end member (90 mm), an end post and a head member close the ends. 14.5 m of tube in all (was 11.75 m). | Every member now butts onto two others and can be welded; a member pair leaves a gap for each vertical shaft; the drop posts are lighter than a third pair of side rails. |
| P2 | The two flanged bearing units (95 mm square flanges) had only a 25 mm tube, or nothing, to bolt to. | A 150 x 130 x 6 mm plate is welded under each pair (spindle pair and tub pair) with a 40 mm centre hole and four bolt holes; each bearing hangs under its plate. Bearing centres are now 255 and 420 mm above the ground, 165 mm apart (were 300 and 450 mm, 150 apart). The driven pulley drops 10 mm, to 180 to 220 mm. | Bolting under the plate keeps both plates welded in one setting, so the two bores line up with a plumb line; the wider span helps the spindle. |
| P3 | The spindle was a solid 25 mm shaft, yet the rotary union at its foot has to feed water to the jacket at its top. | The spindle is a 25 x 2 mm stainless 316 tube, 372 mm long; water runs up its bore. A 1/2 in BSP stainless nipple is welded into its foot to take the union. | No lathe or deep drilling is needed (R10). The thinner section lowers the first critical speed from about 4,820 to 2,710 rpm, still 2.3 times the 1,200 rpm sprint speed; bending stress 21 MPa (GVS-CAL-001 v0.4). |
| P4 | The bowl hub was a plain cylinder that passed through the jacket floor and had no fixing; the jacket was open at its top, so the fluidization water would run out of the 12 mm gap there. | A bought 25 mm bore shaft flange hub (80 mm flange) is pinned to the spindle top and bolted by four M6 bolts through the jacket floor and four 12 mm spacer bushes into four M6 nuts cast into the liner floor. A 4 mm GFRP closing ring is bonded between the shell and the jacket top. | The spacers set the 12 mm gap at the floor; the closing ring seals it at the top, so water can only leave through the ring holes. The bowl, jacket and hub come off the spindle as one unit by pulling one pin. |
| P5 | The riffle rings stand inward from the liner wall, so a one-piece printed core could not be pulled out of the cast liner. | The printed core is made in six segments round a central key: the key comes out first, then each segment moves inward past the rings. The GFRP shell is the outer mould. | Keeps the cast PU liner of GVS-DDR-001 item 4 with no lathe. |
| P6 | The tub's centre hole opened onto the upper bearing, so spilt slurry would run into it; the tailings launder was a box through an uncut tub wall that also ran into the frame. | A 63 mm standpipe, 50 mm tall, stands through a rubber pipe grommet in the tub floor and sits on the upper bearing plate, 10 mm below the hub. The tailings outlet is a 75 mm pipe through a rubber pipe grommet in the back wall, centred 64 mm above the floor, 12.5 mm clear of the frame. Four M8 bolts hold the tub floor on the tub members. | Rubber pipe grommets seal in a curved wall and need no plastic welding. The bowl and hub run clear of the standpipe (12 mm). |
| P7 | The feed pipe ran down through the lid's hole into the bowl, so the lid could not be lifted off for a flush; the hopper's bottom was closed; the hopper arm ended inside the cone. | The feed pipe stops 15 mm above the lid and drops the slurry through the 60 mm hole onto the bowl floor. The hopper bottom has a 32 mm hole into the pipe. The cone drops into a 6 mm ring on the support arm and wedges there; the support post bolts to the front top rail. | The lid now lifts straight off without touching the hopper, so R13's toolless flush stands. |
| P8 | The pedal chain's lower run crossed the jackshaft member; the outrigger's arms ended in the air at the frame end; the seat was too low for the crank. | The bottom bracket rises to 438 mm, 100 mm above the jackshaft (now 338 mm, on two pillow blocks on the gearbox pair), so the chain passes 4.6 mm over the left gearbox member. The outrigger is a welded spine with two cross feet, a pedal post, a round seat tube and a top arm, bolted by two end plates to the low end member and the end post. The saddle sits about 910 to 960 mm up, adjustable on a bicycle seat post. | Uses bought bicycle parts as before; the outrigger lifts off with four bolts for transport. |
| P9 | The gearbox floated. | The gearbox stands across the two gearbox members, four M8 bolts; its output shaft goes down between them to the 300 mm drive pulley. | |
| P10 | The table take-off pulley, inside the frame, ran into the members; and the table belt's loop enclosed the frame's table-end top rail, so the belt could not be fitted. | The jackshaft runs out 330 mm in front of the centre line, past the front rails; the take-off pulley and the table head pulley share a belt plane outside the frame. | Nothing passes between the two runs of the table belt. |
| P11 | The hub motor's body enclosed its own chain (review note of 2026-09-26, item 5) and overlapped the motor member. | The motor option bolts on: a 6 mm cradle on the back lower rail with two dropouts and open axle slots; the motor sits behind the frame with its sprocket on the disc mount, chained to a sprocket on the end of the jackshaft; a chain guard covers it. | The pedal-only machine carries no motor parts; the motor chain clears the hub by 3.5 mm. |
| P12 | The belt guard floated and the spindle and gearbox shaft ran through its top; the table belt had no guard (safety note of 2026-09-26). | The bowl belt guard hangs on four straps from the members, with holes for the two shafts. The pedal chain case rests on the left gearbox member and is tabbed to the pedal post. A table belt guard covers the table belt and its tensioner. | Every belt, chain and pulley is guarded (R12). |
| P13 | The water hose dropped through the belt guard, the drive pulley and the tank post member; the tank post was not drawn (review note of 2026-09-26, item 3). | The tank post and a 250 x 250 x 5 mm cradle with gussets are drawn and welded to the frame. The valve is on the back of the drum; the rotameter is on a bracket on the back top rail; the hose runs down outside the back of the frame, then under the belt guard to the union. | Follows the route proposed in the review note of 2026-09-26 (item 2), adapted to the new frame. |
| P14 | The table legs were solid blocks; the head stood on a single 25 mm post on a foot plate (about 134 MPa under the belt pull, a factor of about 1.8); the table belt had no clutch mechanism; the concentrate tray ran along the front, where the tailings fall, and the deck's front edge overhung it. | Four 18 mm plywood flexure legs on angle cleats, on a welded base, thin side along the table so they bend with the stroke. The head is a 6 mm plate and shelf bolted to the frame's table end, with two pillow blocks, a 20 mm head shaft and an eccentric of 15 mm stroke; a pitman links it to cheeks under the deck. A tensioner (idler on a latched arm) is the table clutch. A tailings launder runs under the deck's front edge; the lockable concentrate box sits under the far end, where gold leaves the riffles. A drilled wash water pipe runs along the back edge (review note of 2026-09-26, item 6). | Uses the frame as the head's anchor (the table runs only when the bowl is stopped), and puts each product where the table delivers it. |
| P15 | The speed display faced away from the rider and the brake caliper's bracket floated. | The display and the brake lever sit on the pedal-end top rail, facing the rider. The caliper sits on a 6 mm L bracket bolted to the right spindle member; the disc sits on a flange welded to a shaft collar. | |

*Table 2. Knock-on changes.*

| Item | Change | Reason |
| --- | --- | --- |
| Mass | 77.3 kg to **95.7 kg** in six loads; heaviest load 25.2 kg (the base frame with the spindle and brake) (GVS-CAL-001 v0.4, section 11). R11 (80 kg) moves from met on paper to **not met, 16 kg over**; every load is still under 30 kg. | About 2.7 m more tube, about 9 kg of plate, and parts the concept left out (hopper support, tank cradle, standpipe and pipes, head plate, tensioner, table belt guard, launder legs). |
| Cost | BOM $455 to **$558**: value-engineering target USD 455; estimated cost of the constructable design USD 558 (USD 103 over the target). Lines 1 to 4, 6, 8, 11, 13 to 17 repriced and line 20 (motor cradle) added. | Parts added for construction. |
| Spindle | First critical speed 4,820 to 2,710 rpm (2.3 times the sprint speed); bending 18 to 21 MPa. | Hollow spindle (P3) and bearing positions (P2). |
| Size | 2.72 x 0.78 x 1.65 m to 2.78 x 0.79 x 1.65 m. | Outrigger feet and the outboard table belt. |
| Drawings | GVS-DWG-001 Rev P3; making sketches GVS-DWG-101 to 120 added. | Follows the model. |
| Documents | GVS-CAL-001 v0.4, GVS-REQ-001 v0.6, GVS-PRC-001 v0.6: mass, cost, spindle and R9, R10, R11 updated. | Follows the model. |
| Table bump stop (A2, carried out in v0.3; the slotted pitman pin and leaning legs accepted by Amish 2026-10-01) | A bracket of 25 mm tube bolted on top of the frame's table-end top rail, 205 mm behind the centre line, carries a bought rubber buffer (40 mm across, 30 mm long, about 55 Shore A) on an M8 stud with a lock nut each side of its upright; a 6 mm steel striker angle under the deck's head end strikes it at the end of each forward stroke. The pitman pin works in a 20 mm slot in the deck cheeks (8 mm of free play), and the plywood legs are set leaning so they press the deck on the buffer with about 200 N. The stop is set 3 mm short of full forward travel (2 to 6 mm useful): 0.24 J per stroke, 2.1 G at the stop against 0.6 G at the head end (GVS-CAL-001 v0.6, section 9). Mass 95.7 to 96.5 kg; cost $558 to $569 (BOM lines 21 and 22); 13 checks added to the model (115 in all); GA Rev P4; making sketch GVS-DWG-121; build plan v0.3. | A rigid pitman drags the deck through the whole circle of the eccentric and cannot strike a stop, so the slot and the legs' push are needed for the stop to make the stroke asymmetric. The concept asked for a "toggle or spring return"; the legs are the spring. |
| Unchanged | Bowl speed, G, drive ratio, power, water, settling, fluidization supply, burst factors, brake and gold balance. | The bowl, jacket and drive geometry did not change. |

*Table 3. Items that change a requirement or what the machine does: proposed, then accepted by Amish as recommended on 2026-10-01.*

| # | Question | Options | Recommendation |
| --- | --- | --- | --- |
| A1 | R11 asks for 80 kg or less in all; the constructable design is about 96 kg, though every load stays under 30 kg (heaviest 25 kg) so two people can still carry each one. | (a) restate R11's total as 100 kg or less, keeping loads of 30 kg or less; (b) find about 16 kg (for example aluminium hopper, guards and launder, 4 mm plates, a lighter table base), then re-estimate; (c) keep 80 kg and leave R11 not met. | (a), because the per-load limit is what decides whether two people can carry the machine to site; try the savings in (b) at TRL 4 anyway. |
| A2 | The concept asks for an asymmetric table stroke ("toggle or spring return"); the model has a plain eccentric on flexure legs, which gives a nearly symmetric stroke, and a symmetric stroke does not walk gold along a shaking table. | (a) add an adjustable rubber bump stop at the return end of the stroke, the simplest way to make the stroke asymmetric; (b) a toggle (Rittinger-type) head; (c) a spring return with a cam. | (a) for the prototype, adjustable by a screw, because it adds one part to the frame end; (b) if the first test shows (a) is not enough. |
| A3 | The pedal position: the saddle is about 910 to 960 mm up and 170 mm behind a bottom bracket at 438 mm. This has not been checked against riders of different sizes. | (a) keep, with the seat post adjustable over about 200 mm; (b) move to a recumbent seat further back. | (a); check at TRL 4 with two riders. |

## Consequences

- `design_state: constructable` in `project.yaml`. The build plan GVS-BLD-001 shows every component and step in pictures generated from the model (`cad/src/build_plan_media.py`); the open questions are in the design decisions register GVS-DEC-001.
- Requirement status: R11 moved to not met (16 kg over 80 kg, every load under 30 kg) and R9 is now reported against the value-engineering target (USD 103 over). R2, R5 and R6 stay at risk, R4 and R14 not verifiable, the rest met on paper or by design review (GVS-CAL-001 v0.4).
- With A1 accepted, R11 is restated to 100 kg or less in all, every load 30 kg or less, and is met on paper at 95.7 kg (GVS-REQ-001 v0.7, GVS-CAL-001 v0.5); the savings of option (b) are to be tried at TRL 4. With A2 accepted, the table stroke is made asymmetric by an adjustable rubber bump stop at the return end (the far end of the forward stroke, where the deck turns back), with a toggle head only if the first test shows it is not enough; the stop is now in the model, the BOM (lines 21 and 22), the calculations (GVS-CAL-001 v0.6, section 9), making sketch GVS-DWG-121 and the build plan (GVS-BLD-001 v0.3, section 3.16 and step 16), as Table 2 describes. With A3 accepted, the pedal position is kept and checked with two riders at TRL 4.
- With the bump stop change accepted (2026-10-01), the pitman pin works in a 12 x 20 mm slot in the deck cheeks with 8 mm of free play, and the plywood legs are set leaning about 5 mm so they press the deck on the buffer with about 200 N; this is the design as drawn in the model, the making sketches and the build plan (GVS-BLD-001 v0.3, sections 3.15 and 3.16). The toggle head of A2, option (b), stays the fallback if the first table test shows the stop is not enough.
- Decisions of 2026-10-02 (GVS-DEC-001), carried into this design the same day: the tank post rises to 1.7 m (cradle at 1,700 mm, post 995 mm) with two braces of the frame tube from 1,350 mm up the post to the front and back top side rails; to stop the taller post making the machine easier to tip, the post now stands on the centre line, not 180 mm behind it (kept open for Amish in GVS-DEC-001); the hose's short run to the rotameter rises to 860 mm to clear the bracket. A bought 10 L flush container with a padlock hasp is BOM item 23. The model runs 126 checks, all passing; mass 99.3 kg; cost $580 (GVS-CAL-001 v0.8); GA Rev P5; making sketch GVS-DWG-101 Rev P2; build plan v0.4.
- The appearance model `cad/src/product_model.py` was rebuilt on 2026-10-02 from the model's components, so it matches the constructable design; the photoreal renders (`media/render-*.png`), `media/card.png` and `media/social-preview.png` still show the concept and need re-rendering on Amish's Mac, where Blender is.
- The bought parts that set dimensions (bearing units, shaft flange hub, rotary union, gearbox, pillow blocks, rubber grommets, hub motor) must be checked against the model when bought; they are listed in GVS-DEC-001.

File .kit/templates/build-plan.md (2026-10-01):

---
doc_id: PRJ-BLD-001
title: Project prototype build plan
project: Project name
doc_type: Build plan
version: "0.1"
status: Draft
date: YYYY-MM-DD
author: Amish Chadha
license: CERN-OHL-S-2.0
revisions:
  - version: "0.1"
    date: YYYY-MM-DD
    author: Amish Chadha
    change: First build plan; design made constructable
---

# Project prototype build plan

**Plan, not yet built.** How to build the first proof-of-concept prototype, component by component. Building and testing to it is TRL 4 work. Decisions still to be made are kept in the design decisions register (`docs/06-design-decisions.md`), not here.

## 1. What you are building

Every component, pulled apart and numbered in build order

One short paragraph: what the prototype is, how many components, which are made and which are bought, and the main ways they are made.

## 2. What changed to make it buildable

| Component | The concept had | The buildable design has | Why |
| --- | --- | --- | --- |

## 3. Making the components

### 3.1 Component name

Making sketch

**What it is and what it is made from.**

**How to make it.**

1. Mark out ...
2. Cut ...

**How it fits the parts next to it.**

Close-up of the joint

**Check before moving on.**

## 4. Putting it together

### Step 1: ...

Step 1

## 5. First checks

| Check | Requirement | How | Pass when |
| --- | --- | --- | --- |

## 6. Safety stops

## 7. Tools, skills and workspace

## 8. Where the numbers come from

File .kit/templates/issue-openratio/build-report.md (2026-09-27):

---
name: Build report
about: Tell us what happened when you built, printed or tested part of this design
title: "Build report: "
labels: build-report
---

This is a research and educational prototype, not a medical device. It is a TRL 3 concept and is not released for fabrication. If you build any part of it, you do so at your own risk. Reports help everyone.

**What you built** (part, sub-assembly or test)

**Materials, tools and settings**

**What worked**

**What did not work, with photos or measurements if you have them**

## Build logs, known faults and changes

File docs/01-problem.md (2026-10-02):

---
doc_id: GVS-PRB-001
title: GravitySort problem statement
project: GravitySort
doc_type: Problem statement
version: "0.7"
status: Draft
date: '2026-10-02'
author: Amish Chadha
license: CERN-OHL-S-2.0
revisions:
- version: "0.1"
  date: '2026-09-25'
  author: Amish Chadha
  change: Initial scaffold
- version: "0.2"
  date: '2026-09-25'
  author: Amish Chadha
  change: Populate to TRL 2 (problem, users, context, constraints, out of scope, prior work with sources)
- version: "0.3"
  date: '2026-09-25'
  author: Amish Chadha
  change: TRL 3 update. Cost and power constraints from GVS-CAL-001; water pumping gap; partner screening criterion and borax smelting step adopted for TRL 3 under Amish's 2026-09-25 instruction (GVS-DDR-001), open for his review
- version: "0.4"
  date: '2026-09-25'
  author: Amish Chadha
  change: Recommendations accepted by Amish (DDR-002). Budget $450; borax smelting step and partner screening criterion decided
- version: "0.5"
  date: '2026-09-26'
  author: Amish Chadha
  change: Budget approved by Amish ($455)
- version: "0.6"
  date: '2026-10-01'
  author: Amish Chadha
  change: Budget worded as a value-engineering target; cost of the constructable design (GVS-DDR-003)
- version: "0.7"
  date: '2026-10-02'
  author: Amish Chadha
  change: "Site water and first partner as decided on 2026-10-02 (GVS-DEC-001)"
---

# GravitySort problem statement

Artisanal and small-scale gold miners use mercury to catch fine gold because it is cheap, needs no power and works well enough, and the mercury ends up in their bodies, their homes and their rivers. Mercury-free gravity equipment exists, but the machines that catch fine gold (centrifugal concentrators and shaking tables) are costly and mostly imported, and cheap sluices lose much of the fine gold. Design with, not for: requirements must come from co-design sessions and field trials with the intended users through a local partner.

## The problem

Artisanal and small-scale gold mining (ASGM) is the largest source of human-made mercury emissions to air, at about 838 t in 2015, or 37.7 % of the global total ([US EPA summary of the UNEP Global Mercury Assessment 2018](https://www.epa.gov/international-cooperation/mercury-emissions-global-context)). UNEP estimates that 10 to 15 million people work in the sector, including 4 to 5 million women and children ([UNEP Global Mercury Partnership](https://www.unep.org/globalmercurypartnership/what-we-do/artisanal-and-small-scale-gold-mining-asgm)).

Mercury is used because it solves a real processing problem. Much of the gold in milled ore is fine (below about 0.1 mm), and fine gold is hard to hold on a sluice. Miners add mercury, which wets gold and forms an amalgam that is easy to collect, then burn off the mercury over an open fire to leave sponge gold. The two worst practices are whole-ore amalgamation, where mercury is mixed with all of the ore rather than a small concentrate, and open burning of amalgam. Both are named for elimination in Annex C of the Minamata Convention on Mercury ([Minamata Convention guidance on national action plans](https://minamataconvention.org/sites/default/files/documents/forms_and_guidance_document/ASGM_guidance_e_2017.pdf)).

Mercury is also not as good as it looks. In Colombian processing centers where whole ore is amalgamated in small ball mills, gold recovery is typically about 30 %, and a study of simple gravity and flotation equipment built from local materials found that concentration can be more profitable when recovery is higher than that ([Veiga et al., *Journal of Cleaner Production* 205, 2018](https://doi.org/10.1016/j.jclepro.2018.09.039)). The obstacle is less the physics than access: gravity equipment that catches fine gold is "generally more expensive" and "requires some experience to operate" ([US EPA, ASGM without mercury](https://www.epa.gov/international-cooperation/artisanal-and-small-scale-gold-mining-without-mercury)).

GravitySort addresses the equipment gap: an open, garage-buildable centrifugal concentrator and small shaking table, powered by pedals or a small electric motor, that together make a clean concentrate small enough to smelt directly with borax, so no mercury is needed at any step.

## Users and context

Table 1. Intended users. Proposed for review; the real list must come from co-design sessions.

| User | Need | Context |
| --- | --- | --- |
| Small mining group (3 to 10 people) | Recover more of the gold in the ore they already mine, without mercury, at a cost they can recover in weeks | Hard-rock or alluvial pits; ore milled by hammer mill or ball mill to below about 1 to 2 mm |
| Processing center (entable, plant) operator | Replace whole-ore amalgamation with a concentrate step to meet new rules and keep customers | Mills ore for many miners on a fee basis; has mains or generator power |
| Women processors | A safer role than panning with mercury at home or at the river | Often handle panning, washing and amalgam burning today |
| Local workshop or welder | Build, repair and sell the machine with local tools and materials | Welding set, drill press, hand tools; no lathe in many cases |
| NGO, cooperative or extension officer | Demonstrate mercury-free processing with miners and measure recovery | Programmes under national ASGM action plans; planetGOLD and similar |

### Operating environment

- **Feed:** ore milled to below 2 mm, as a slurry of about 25 to 35 % solids by mass; gold grades from about 1 to 20 g/t; heavy minerals such as magnetite, pyrite and hematite in the feed.
- **Sites:** remote pits and camps, often in tropical forest or savanna, sometimes at altitude; dust, mud, rain and heat (15 to 40 °C).
- **Water:** often scarce or silt-laden; recirculation through a settling pond is good practice and increasingly required.
- **Power:** frequently none, or a small generator shared with the mill.
- **Security:** gold concentrate is valuable and theft is a real concern, so concentrate must be easy to lock away.
- **Supply chain:** steel tube, sheet metal, bicycle parts, bearings, V-belts, HDPE drums and hoses are sold in most mining towns; specialist parts are not.

## Constraints

- Garage-buildable prototype. Value-engineering target: USD 455 in parts, a hypothetical control target rather than a limit (Amish, 2026-10-01; raised from $350 to $450 on 2026-09-25 and to $455 on 2026-09-26, GVS-DDR-002). Estimated cost of the constructable design: USD 558 (USD 103 over the target; GVS-CAL-001 v0.4).
- No mercury in any step, and no chemicals beyond water and, at the smelting step outside this machine, borax flux.
- Built with welding, drilling and hand tools; parts that normally need a lathe (bowl, spindle) must have a no-lathe route.
- Runs without grid power: pedal drive as the baseline, with an optional motor through MotionCore on a pack of the user's choice. The water supply (about 1.19 m3/h) comes by gravity from upstream as the site rule for the first field trial, or from a bought treadle or hand pump or a 12 V pump where that is impossible (decided by Amish, 2026-10-02, GVS-DEC-001).
- Carried to site in parts by two people and assembled with hand tools.

## Out of scope

- Milling and crushing (a separate machine; GravitySort starts from milled ore).
- Cyanide leaching, flotation and any chemical processing.
- Smelting equipment. Direct smelting with borax is the recommended final step (decided by Amish, 2026-09-25: go with recommendation; GVS-DDR-002) and the concentrate is sized for it, but the furnace is not part of this design.
- Tailings dams and water treatment beyond a settling pond.
- Legal status, licensing and the gold trade. These decide whether any equipment is adopted and must be covered by the partner organization.

## Prior work

- **Commercial centrifugal concentrators** (Knelson, Falcon and similar) use a spinning riffled bowl, often fluidized with water, to hold dense particles at tens of times gravity. They are effective on fine gold but costly, and small units run batch cycles of about 0.5 to 2 h ([US EPA](https://www.epa.gov/international-cooperation/artisanal-and-small-scale-gold-mining-without-mercury)).
- **Shaking tables** give high-grade concentrates but are "relatively expensive and require some experience to operate" ([US EPA](https://www.epa.gov/international-cooperation/artisanal-and-small-scale-gold-mining-without-mercury)).
- **CICAN project, Colombia.** A chain mill, shaking table and flotation cell were built from junkyard and workshop materials for micro-miners processing under 2 t per day, with capital costs of US$2,600 to US$10,500 ([Veiga et al., 2018](https://doi.org/10.1016/j.jclepro.2018.09.039)). GravitySort aims below the bottom of that range for the concentration step alone.
- **Direct smelting with borax (Benguet method).** Small-scale miners in Benguet, Philippines, smelt gravity concentrates with borax instead of amalgamating them; the Benguet federation reports that its 15,000 members use the method ([Pure Earth](https://www.pureearth.org/filipino-gold-miners-borax-revolution/); [Appel and Na-Oy, *Journal of Health and Pollution*, 2012](https://www.journalhealthpollution.org/doi/full/10.5696/2156-9614-2.3.5)). The method needs a small, clean concentrate; the US EPA cites about 50 to 100 g ([US EPA](https://www.epa.gov/international-cooperation/artisanal-and-small-scale-gold-mining-without-mercury)).
- **planetGOLD** runs mercury-free ASGM programmes, including equipment and finance, in many countries ([planetGOLD](https://www.planetgold.org/about)).

The gap GravitySort targets is an open design that combines the fine-gold capture of a centrifuge with the upgrading of a table, at a parts cost a small group can afford, and that runs on pedal power.

## Open questions

- [ ] What gold particle size distribution do partner sites actually have, and how much of the gold is locked in sulfides that no gravity method will recover?
- [ ] Is pedal power acceptable for a full shift, or will users treat the motor as the default?
- [ ] How much water is available per site, and is recirculation practical?
- [ ] Which country's national action plan and partner offers the best first field site? The screening criterion (GVS-DDR-001 item 8a; decided by Amish, 2026-09-25: go with recommendation) is a country with a mercury ban in force, such as Colombia, or a Minamata action plan with a planetGOLD programme; the partner itself was decided by Amish on 2026-10-02 (GVS-DEC-001): Colombia, with a miners' cooperative introduced through the Alliance for Responsible Mining in Medellin as the first candidate to approach.
- [ ] How do sites without power get about 1.2 m3/h of water to the header tank? Gravity supply from upstream is the site rule for the first trial, with a treadle, hand or 12 V pump as the fallback (GVS-DEC-001); to be checked at the partner's sites.

## User research and co-design

This design is for communities the author is not part of, so requirements come from the people who will use it.

- [ ] Identify a local partner organization (Helpful Engineering network, NGO or university)
- [ ] Run co-design sessions with intended users; record who, where and what was learned
- [ ] Validate load, distance, terrain and cost assumptions in the field
- [ ] Revise requirements (REQ) from findings before freezing the design

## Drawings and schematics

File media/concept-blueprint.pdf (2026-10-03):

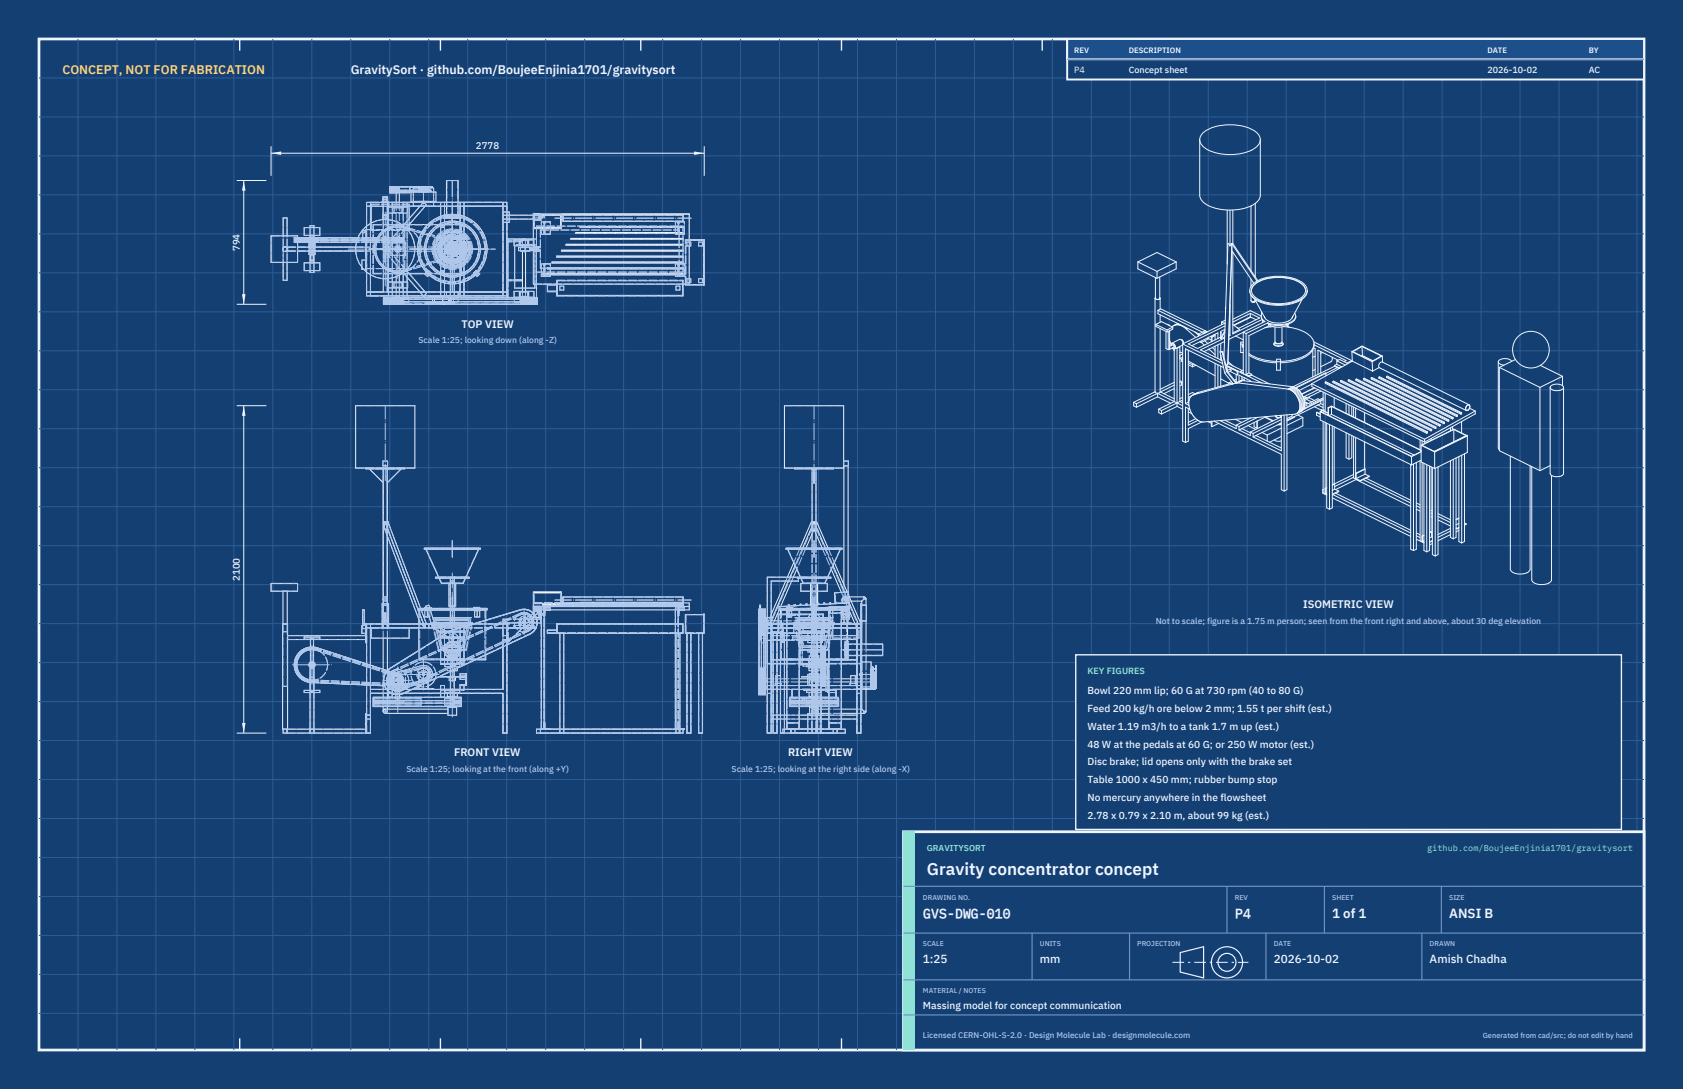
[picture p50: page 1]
CONCEPT, NOT FOR FABRICATION; GravitySort · github.com/BoujeeEnjinia1701/gravitysort; FRONT VIEW; TOP VIEW; RIGHT VIEW; ISOMETRIC VIEW; REV; DESCRIPTION; DATE; Concept sheet; GRAVITYSORT; github.com/BoujeeEnjinia1701/gravitysort; DRAWING NO. GVS-DWG-010; REV P4; SHEET 1 of 1; SIZE ANSI B; SCALE 1:25; UNITS mm; PROJECTION; DRAWN Amish Chadha; Licensed CERN-OHL-S-2.0 · Design Molecule Lab · designmolecule.com; Generated from cad/src; do not edit by hand

Scale 1:25; looking down (along -Z)

Not to scale; figure is a 1.75 m person; seen from the front right and above, about 30 deg elevation

KEY FIGURES
Bowl 220 mm lip; 60 G at 730 rpm (40 to 80 G)
Feed 200 kg/h ore below 2 mm; 1.55 t per shift (est.)
Water 1.19 m3/h to a tank 1.7 m up (est.)
48 W at the pedals at 60 G; or 250 W motor (est.)
Disc brake; lid opens only with the brake set
Table 1000 x 450 mm; rubber bump stop
No mercury anywhere in the flowsheet
2.78 x 0.79 x 2.10 m, about 99 kg (est.)

Scale 1:25; looking at the front (along +Y)

Scale 1:25; looking at the right side (along -X)

Gravity concentrator concept

MATERIAL / NOTES
Massing model for concept communication

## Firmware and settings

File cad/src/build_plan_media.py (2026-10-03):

"""GravitySort prototype build plan pictures (GVS-BLD-001, STANDARDS section 18).

Run from the repo root:  python cad/src/build_plan_media.py [overview|sheets|joints|steps|layouts ...]
A sheet, joint or step can be drawn alone:  python cad/src/build_plan_media.py sheet 101  (or joint 3, step 7)
With no argument it draws everything. Every picture is drawn from cad/src/model.py
(build_components), so the pictures and the model never disagree:
    docs/05-build-plan/overview.png        every component pulled apart, numbered in build order
    cad/drawings/GVS-DWG-101 to 121        making sketches for the made and modified components
    docs/05-build-plan/joint-NN.png        close-ups of the joints that need explaining
    docs/05-build-plan/step-NN.png         one picture per assembly step
    docs/05-build-plan/frame-cuts.png      frame cut list and member positions (matplotlib)
Uses .kit/build_views.py. BUILD PLAN ILLUSTRATION, PLAN NOT YET BUILT.
"""
import math
import sys
from pathlib import Path

ROOT = Path(__file__).resolve().parents[2]
sys.path[:0] = [str(ROOT / ".kit"), str(ROOT / "cad" / "src")]
import build_views as bv  # noqa: E402
from build_views import Part  # noqa: E402
from model import PARAMS as P, build_components, derived, frame_members, brace_ends, brace_length, _box, _cyl, _cyly, _fuse  # noqa: E402

OUT = ROOT / "docs" / "05-build-plan"
DWG = ROOT / "cad" / "drawings"
DATE = "2026-10-01"
DATE2 = "2026-10-02"          # sheets and pictures revised for the decisions of 2026-10-02
D = derived(P)
C = build_components(P)
S = lambda *ks: _fuse([C[k].shape for k in ks])  # noqa: E731
BOLT = "#111827"


def part(name, shape, color, explode=(0, 0, 0), alpha=1.0):
    return Part(name, shape, color, None, tuple(explode), alpha)


def cp(key, name=None, explode=(0, 0, 0), color=None):
    c = C[key]
    return part(name or c.name, c.shape, color or c.color, explode)


def grp(name, keys, color, explode=(0, 0, 0)):
    return part(name, S(*keys), color, explode)


def win(shape, x0, x1, y0, y1, z0, z1):
    return shape & _box(x0, x1, y0, y1, z0, z1)


# ----------------------------------------------------------------- named groups, in build order
GROUPS = [
    ("Base frame with bearing plates, tank post braces and cradle", ("frame", "tank_braces", "bearing_plates", "tank_cradle"), "#4B5563"),
    ("Pedal outrigger and seat", ("outrigger", "outrigger_plates", "seat"), "#374151"),
    ("Jackshaft, bearings, gearbox, pulleys", ("pillow_blocks", "gearbox", "jackshaft", "jack_wheels", "drive_pulley"), "#78716C"),
    ("Crankset and pedal chain", ("crankset", "pedal_chain"), "#1F2937"),
    ("Spindle, bearings, brake disc, pulley", ("spindle", "bearings", "brake_flange", "rotor", "driven_pulley"), "#9CA3AF"),
    ("Rotary union", ("union",), "#B45309"),
    ("Bowl belt", ("bowl_belt",), "#111827"),
    ("Belt guard and speed sensor", ("belt_guard", "sensor"), "#CA8A04"),
    ("Pedal chain case", ("chain_case",), "#EAB308"),
    ("Brake caliper and bracket", ("caliper", "caliper_bracket"), "#DC2626"),
    ("Splash tub, standpipe, tailings pipe", ("tub", "standpipe", "tail_pipe"), "#60A5FA"),
    ("Bowl: liner, shell, jacket, hub", ("liner", "shell", "jacket", "hub"), "#0F766E"),
    ("Lid guard and clamps", ("lid", "clamps"), "#1F2937"),
    ("Hopper support", ("hopper_post",), "#6B7280"),
    ("Hopper and screen", ("hopper", "screen"), "#D97706"),
    ("Header tank", ("tank",), "#38BDF8"),
    ("Valve, rotameter and hose", ("valve_meter", "hose"), "#0369A1"),
    ("Speed display and brake lever", ("display", "brake_lever"), "#7C3AED"),
    ("Table base", ("table_base",), "#6B7280"),
    ("Flexure legs and cleats", ("flex_legs", "cleats"), "#A16207"),
    ("Table deck and wash pipe", ("deck", "wash_pipe"), "#C9A27E"),
    ("Table head, bump stop and striker", ("head", "head_bearings", "head_shaft", "stop_bracket", "bump_stop", "striker"), "#57534E"),
    ("Pitman arm", ("pitman",), "#B45309"),
    ("Table belt, tensioner and guard", ("table_belt", "tensioner", "table_guard"), "#0F766E"),
    ("Tailings launder and concentrate box", ("launder", "conc_box"), "#92400E"),
    ("Motor option: cradle, motor, chain, module", ("motor_cradle", "motor", "motor_chain", "motor_guard", "mcore"), "#15803D"),
    ("Flush container with padlock hasp (loose)", ("flush_box", "flush_staple", "flush_hasp"), "#9CA3AF"),
]


def overview():
    off = [(0, 0, 0), (-550, 0, 0), (-150, 0, -700), (-650, -350, 750), (250, 0, -800), (250, 0, -1100), (-150, 0, -1000),
           (-150, 0, -1300), (-550, -450, 0), (550, -200, -700), (0, 0, 700), (0, 0, 1050), (0, 0, 1400), (0, -450, 1100),
           (0, 0, 1750), (-350, 250, 250), (0, 900, -150), (-700, 0, 700), (1050, 0, -450), (1050, 0, -150), (1050, 0, 300),
           (550, 0, 150), (650, -350, 450), (700, -450, -1350), (1050, -700, -150), (0, 1300, 0), (-700, -500, 0)]
    parts = [grp(n, ks, col, off[i]) for i, (n, ks, col) in enumerate(GROUPS)]
    return bv.overview(parts, OUT / "overview.png", "GravitySort prototype: every component, pulled apart",
                       subtitle="Numbered in build order; 26 is the motor option, 27 the loose flush container. Seen from the front right and above",
                       elev=20, azim=-62, size=(12, 8.5), dpi=150, key=True)



# ----------------------------------------------------------------- making sketches
def flat(shape, origin, x_dir, z_dir):
    import build123d as b
    return b.Plane(origin=origin, x_dir=x_dir, z_dir=z_dir).to_local_coords(shape)


def ctx(*keys, color=None):
    return [cp(k) for k in keys]


SHEETS = {}


def sheet(n):
    def deco(fn):
        SHEETS[n] = fn
        return fn
    return deco


def _sheet(key, neighbours, dwg, title, material, notes, view_shape=None, inset=(22, -60), shape=None, name=None, rev="P1", revisions=None,
           date=DATE):
    pt = Part(name or C[key].name, shape if shape is not None else C[key].shape, C[key].color if key in C else "#6B7280")
    return bv.component_sheet(pt, [cp(k) for k in neighbours], project="GravitySort", dwg_no=dwg, title=title,
                              material=material, notes=notes, date=date, view_shape=view_shape, inset_view=inset,
                              out_dir=str(DWG), rev=rev, revisions=revisions)


P1 = ("P1", "Making sketch for the prototype build plan", "2026-10-01", "AC")


@sheet(101)
def s101():
    import build123d as b
    fr = S("frame", "tank_braces", "bearing_plates", "tank_cradle")
    return _sheet("frame", ["outrigger", "tub", "gearbox", "pillow_blocks"], "GVS-DWG-101",
                  "GravitySort base frame: making sketch", "Mild steel square tube 25 x 25 x 1.5 mm; plate 5 and 6 mm",
                  ["Cut list (frame cut picture in the plan gives every position):",
                   "  4 legs 700; 4 side rails 850 (top pair and lower pair, 255 up);",
                   "  2 top end rails, low end member (90 up), head member (600 up), 550;",
                   "  6 members 600 laid across: gearbox pair, spindle pair on top of",
                   "  the lower rails, tub pair hung on 4 drop posts 205 at 445 up;",
                   f"  tank post member 550, end post 560, tank post {P['tank_z'][0] - P['rail_z'] - 5:.0f};",
                   f"  2 tank post braces {brace_length():.0f}, mitred. {sum(l for _, l in frame_members()) / 1000:.1f} m in all.",
                   "Tack on a flat floor, check diagonals within 2 mm, then weld.",
                   "Bearing plates 150 x 130 x 6, 40 mm centre hole, four 11 mm holes",
                   "  70 apart: one under the spindle pair, one under the tub pair,",
                   "  centres in line (plumb bob) before welding.",
                   "Tank post on the centre line; cradle 250 x 250 x 5 on top,",
                   f"  {P['tank_z'][0]:.0f} up, two gussets each way. Braces from {P['brace_z']:.0f} up",
                   f"  the post to the front and back top rails, {P['brace_dx']:.0f} toward the table.",
                   "Drill the bolt holes each later section lists; prime and paint.",
                   "Check: frame sits on all four feet; bearing plate holes in line."],
                  shape=fr, inset=(20, -55), rev="P2", date=DATE2,
                  revisions=[P1, ("P2", "Tank post 1.7 m with two braces, on the centre line (GVS-DEC-001)", DATE2, "AC")])


@sheet(102)
def s102():
    return _sheet("outrigger", ["frame", "crankset", "seat", "chain_case"], "GVS-DWG-102",
                  "GravitySort pedal outrigger: making sketch", "Square tube 25 x 25 x 1.5; round tube 32 x 2; plate 6 mm",
                  ["Spine 529 on the ground, toward the frame; cross feet 400 (seat end)",
                   "  and 300 (under the pedal post), welded under it.",
                   "Pedal post 393 tall on the spine, 185 from its far end; weld a",
                   "  bottom bracket shell cut from a scrap bicycle frame on top, its",
                   "  axis across the machine, centre 438 above the ground.",
                   "Seat tube: round 32 x 2 tube, 675 long, 172 behind the pedal post;",
                   "  slot its top 40 mm and fit a bicycle seat clamp.",
                   "Top arm 504 from the seat tube to the frame end, 600 to 625 up.",
                   "End plates 80 wide, 6 mm, welded across the spine end (125 tall)",
                   "  and the top arm end (65 tall); two 9 mm holes in each.",
                   "Fit: the lower plate bolts to the low end member, the upper plate",
                   "  to the end post; four M8 bolts. Outrigger 6 mm clear of the frame.",
                   "Check: bottom bracket axis square to the spine and level."],
                  shape=S("outrigger", "outrigger_plates"), inset=(18, -40))


@sheet(103)
def s103():
    import build123d as b
    return _sheet("spindle", ["bearings", "bearing_plates", "driven_pulley", "rotor", "hub", "union"], "GVS-DWG-103",
                  "GravitySort spindle: making sketch", "Stainless 316 tube 25 x 2 mm, 372 long; 1/2 in BSP nipple",
                  ["Cut 372 long, square both ends; deburr the bore.",
                   "Water runs up the bore from the rotary union to the jacket.",
                   "Bottom end: weld (TIG) a 1/2 in BSP stainless hex nipple into the",
                   "  bore so its thread stands below the tube for the union.",
                   "Positions from the bottom end: driven pulley 16 to 56; lower",
                   "  bearing 71 to 111; brake collar 173 to 196; upper bearing 236",
                   "  to 276; hub 341 to 368; top end flush with the jacket floor.",
                   "Drill a 6 mm cross hole for the hub pin 349 from the bottom end.",
                   "File a small flat for each bearing set screw.",
                   "Fit: two flanged bearing units under the plates, set screws on",
                   "  the flats; spindle turns freely by hand before the bowl goes on.",
                   "Check: straight within 0.2 mm over its length (roll it on glass)."],
                  view_shape=b.Pos(-P["bowl_x"], 0, -164) * C["spindle"].shape, inset=(15, -50))


@sheet(104)
def s104():
    import build123d as b
    return _sheet("shell", ["liner", "hub", "spindle"], "GVS-DWG-104",
                  "GravitySort bowl shell: making sketch", "Glass fibre and epoxy (GFRP), 4 mm, hand laid",
                  ["A cone cup: 148 across the base, 244 across the lip, 192 tall.",
                   "Print a plug the shape of the liner's outside (146 to 236 across,",
                   "  188 tall), sand it smooth and wax it.",
                   "Lay up 4 mm of glass mat and epoxy over the plug; cure, trim the",
                   "  lip square at 192 and pull the plug.",
                   "Floor: four 6 mm holes on a 60 mm circle, at 45 degrees to the",
                   "  machine axes, for the bowl bolts.",
                   "The shell is the outer mould for the liner (sketch 105).",
                   "After the liner is cast: drill about 89 holes of 1.0 mm through",
                   "  shell and liner into the four ring grooves, more in the lower",
                   "  grooves, so jacket water reaches every groove.",
                   "Check: wall 4 mm, plus or minus 0.5, all round (callipers at the lip)."],
                  view_shape=b.Pos(-P["bowl_x"], 0, 0) * C["shell"].shape, inset=(25, -55))


@sheet(105)
def s105():
    import build123d as b
    return _sheet("liner", ["shell", "jacket"], "GVS-DWG-105",
                  "GravitySort bowl liner: making sketch", "Cast polyurethane, Shore 80 to 90A, 8 mm",
                  ["Inside: 130 across the floor, 220 across the lip, 180 deep.",
                   "Four riffle rings, 6 thick, standing 12 in from the wall, the first",
                   "  50 above the floor, then every 38.",
                   "Core: print the inside shape (with the ring grooves) in six",
                   "  segments round a central key, so it comes out past the rings:",
                   "  pull the key, then lift the segments inward one by one.",
                   "Set four M6 stainless nuts on the shell floor over its holes,",
                   "  bolts through from below to hold them, release-coated threads.",
                   "Centre the core in the shell on its lip spigot; pour the",
                   "  polyurethane slowly from one side; cure as the maker says.",
                   "The liner bonds to the shell; it is replaced with the shell.",
                   "Check: no voids at the ring lips; floor 8 mm thick over the nuts."],
                  view_shape=b.Pos(-P["bowl_x"], 0, 0) * C["liner"].shape, inset=(25, -55))


@sheet(106)
def s106():
    import build123d as b
    return _sheet("jacket", ["shell", "hub", "spindle"], "GVS-DWG-106",
                  "GravitySort fluidization jacket: making sketch", "GFRP 4 mm, hand laid; closing ring 4 mm GFRP sheet",
                  ["A cone cup round the shell with a 12 mm water gap: inside 172",
                   "  across the floor, 253 at the top, 178 tall; outside 180 to 261.",
                   "Print a plug 12 mm bigger all round than the shell; lay up 4 mm.",
                   "Floor: 25.5 mm centre hole for the spindle; four 6 mm holes on",
                   "  a 60 mm circle, lined up with the shell's.",
                   "Closing ring: 4 mm GFRP annulus, 253 outside, 229 inside.",
                   "Fit: four 12 mm spacer bushes stand on the jacket floor over its",
                   "  holes; lower the bowl in, bolt through from below (M6), then",
                   "  bond the closing ring between the shell and the jacket top",
                   "  with epoxy. Seal the spindle hole with an O-ring.",
                   "Check: fill through the spindle at 10 kPa; no leak at the ring;",
                   "  water comes out of every groove hole."],
                  view_shape=b.Pos(-P["bowl_x"], 0, 0) * C["jacket"].shape, inset=(25, -55))


@sheet(107)
def s107():
    import build123d as b
    return _sheet("tub", ["frame", "standpipe", "tail_pipe", "lid"], "GVS-DWG-107",
                  "GravitySort splash tub: making sketch", "HDPE drum, 430 mm across, 6 mm wall (used food-grade drum)",
                  ["Cut the drum 320 above its own floor; the drum floor is the tub",
                   "  floor. File the rim smooth and level.",
                   "Floor: 76 mm centre hole for the standpipe grommet; four 9 mm",
                   "  holes 62.5 each side of centre along the machine and 150 each",
                   "  side across it, onto the two tub members.",
                   "Back wall: 98 mm hole, centre 64 above the floor, on the line",
                   "  through the tub centre toward the back, for the tailings pipe.",
                   "Lid clamps: drill their bases 45 degrees each side of the front.",
                   "Fit: standpipe (63 mm pipe, 50 long) through its grommet, sitting",
                   "  on the upper bearing plate; tailings pipe through its grommet.",
                   "Check: fill 50 mm deep with water; no leaks at either grommet."],
                  view_shape=b.Pos(-P["bowl_x"], 0, 0) * C["tub"].shape, inset=(22, -55))


@sheet(108)
def s108():
    import build123d as b
    return _sheet("lid", ["tub", "clamps", "hopper"], "GVS-DWG-108",
                  "GravitySort lid guard: making sketch", "HDPE sheet 10 mm",
                  ["A disc 446 across, 10 thick, with a 60 mm feed hole in the centre.",
                   "Cut with a jigsaw to a scribed circle; file the edge smooth.",
                   "The lid rests on the tub rim; it overhangs 8 mm all round.",
                   "Two over-centre clamps on the tub, 45 degrees each side of the",
                   "  front, hook over the lid edge; no tools to open or close.",
                   "The right-hand clamp's lever carries the interlock pin on the",
                   "  brake cable: it cannot open unless the brake is set.",
                   "The feed pipe stops 15 mm above the lid: the lid lifts straight",
                   "  up and off without moving the hopper.",
                   "Check: with the clamps shut the lid cannot be lifted by hand."],
                  view_shape=b.Pos(-P["bowl_x"], 0, 0) * C["lid"].shape, inset=(28, -60))


@sheet(109)
def s109():
    import build123d as b
    return _sheet("hopper", ["hopper_post", "screen", "lid"], "GVS-DWG-109",
                  "GravitySort feed hopper: making sketch", "Galvanized sheet 1.2 mm; steel tube 44 x 6; stainless screen",
                  ["Cone 140 across the bottom, 340 across the top, 220 tall.",
                   "Flat pattern: a ring sector, inner radius 169, outer radius 411,",
                   "  149 degrees, plus a 15 mm seam lap. Roll, rivet the seam, seal.",
                   "Bottom: a 140 mm disc with a 32 mm hole, riveted and sealed.",
                   "Feed pipe 44 x 6, 145 long, welded or bonded under the hole.",
                   "Screen: 2 mm punched stainless sheet in a 360 mm flat bar rim,",
                   "  resting on the hopper rim (lifts off for cleaning).",
                   "Fit: the cone drops into the support ring and wedges there.",
                   "The pipe end is 15 above the lid and over the bowl centre.",
                   "Check: water poured in runs out of the pipe with none at the seam."],
                  view_shape=b.Pos(-P["bowl_x"], 0, 0) * C["hopper"].shape, inset=(22, -55))


@sheet(110)
def s110():
    return _sheet("hopper_post", ["frame", "hopper", "lid"], "GVS-DWG-110",
                  "GravitySort hopper support: making sketch", "Square tube 25 x 25 x 1.5; plate 6 mm",
                  ["Foot plate 75 x 25 x 6 with two 9 mm holes 50 apart.",
                   "Post 294 tall welded upright on the foot plate.",
                   "Arm 175 welded to the post top, pointing to the back.",
                   "Ring: 6 mm plate, 176 inside, 216 outside, welded flat on the",
                   "  arm end; its inside edge is the cone's size 40 above its bottom.",
                   "Fit: the foot bolts on the front top rail at the bowl centre line",
                   "  (two M8). The ring centre must sit over the spindle centre:",
                   "  check with a plumb line from the ring to the spindle top.",
                   "Lift off with two bolts for transport.",
                   "Check: ring level; hopper sits in it without rocking."],
                  inset=(22, -55))


@sheet(111)
def s111():
    return _sheet("belt_guard", ["frame", "drive_pulley", "driven_pulley", "bowl_belt", "bearings"], "GVS-DWG-111",
                  "GravitySort bowl belt guard: making sketch", "Perforated steel sheet 1.2 mm; flat bar 25 x 3",
                  ["A shallow box round both pulleys: 566 x 316 x 60 tall.",
                   "Fold a tray (bottom and sides) and a separate lid (top), so the",
                   "  belt can be fitted and checked with the tray off.",
                   "Top: 40 mm holes over the gearbox shaft and the spindle.",
                   "Bottom: 32 mm hole for the spindle foot; the union stays below.",
                   "Four hangers 25 x 3 flat bar, 50 tall, bolted to the top and to",
                   "  the undersides of a gearbox member and a spindle member.",
                   "Speed sensor: on a bracket under the top, beside the driven pulley.",
                   "Fit: 6 mm clear of both pulleys and the belt all round.",
                   "Check: no finger can reach a pulley through any opening.",
                   "Never run the machine with this guard off."],
                  inset=(-30, -60))


@sheet(112)
def s112():
    import build123d as b
    return _sheet("chain_case", ["outrigger", "crankset", "gearbox", "pillow_blocks"], "GVS-DWG-112",
                  "GravitySort pedal chain case: making sketch", "Steel sheet 1.2 mm",
                  ["Two side plates shaped round both sprockets, 12 mm outside the",
                   "  chain, joined by a 26 mm rim strip; 703 long, 253 tall.",
                   "Holes: 28 mm for the crank axle and for the jackshaft.",
                   "Where it crosses the left gearbox member the bottom is flat and",
                   "  rests on the member (one M6 bolt).",
                   "Tab 25 wide to the pedal post (one M6 bolt).",
                   "Make the outer plate removable for fitting the chain.",
                   "Fit: inner plate 4 mm off the gearbox; outer plate 2 mm inside",
                   "  the crank arm.",
                   "Check: turn the cranks a full turn; nothing rubs."],
                  view_shape=flat(C["chain_case"].shape, (0, 0, 0), (1, 0, 0), (0, 1, 0)), inset=(20, -125))
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

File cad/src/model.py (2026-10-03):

"""GravitySort parametric model (build123d), TRL 3, constructable design (GVS-DDR-003).

Header tank post 1.7 m, braced, and a flush container with a padlock hasp (decisions of 2026-10-02, GVS-DEC-001).

Run from the repo root:
    python cad/src/model.py            exports STEP and STL into cad/step and cad/stl, prints the
                                       main envelopes and the constructability checks
    python cad/src/model.py --check    prints the constructability checks only

Every component is modelled as it is made or bought: tube members butt between the members they
weld to, plates carry the bearings, the hopper drops into a ring, the outrigger bolts to the frame
end, and so on (GVS-DDR-003 lists each change from the concept). Tube is modelled solid; its
mass is taken from the cut lengths in frame_members(). Still not fabrication detail: no
tolerances, weld sizes or thread callouts. PRELIMINARY, NOT FOR FABRICATION.

Axes: X along the machine (pedal station at -X, shaking table at +X), Y front (-Y) to back (+Y),
Z up from the ground. Units mm. The centrifuge axis is at (bowl_x, 0).
docs/04-calcs/sizing.py (GVS-CAL-001) imports PARAMS, riffle_rings(), frame_members(),
outrigger_members(), stand_members() and plate_list() so the calculation note and the geometry
use the same numbers. cad/src/build_plan_media.py draws the build plan from build_components().
"""
import math
import sys
from dataclasses import dataclass
from pathlib import Path

# Top-level parameters (mm). Edit these, not the geometry below.
PARAMS = {
    # Base frame (item 1): 25 x 25 x 1.5 mm mild steel square tube (GVS-DDR-002)
    "frame_x0": -450.0, "frame_x1": 450.0, "frame_y": 300.0, "rail_z": 700.0, "tube": 25.0, "tube_wall": 1.5,
    "low_rail_z": 255.0,          # bottom of the lower side rails (the members sit on top of them)
    "mid_z": 445.0,               # bottom of the tub members, hung from the top rails by drop posts
    "end_low_z": 90.0,            # bottom of the low end member at the pedal end
    "head_member_z": 600.0,       # bottom of the head member at the table end
    "plate_t": 6.0,               # bearing plates, cradle, brackets
    # Centrifuge axis and bowl (item 3): cast PU liner on a GFRP shell
    "bowl_x": 100.0,
    "bowl_lip_d": 220.0, "bowl_base_d": 130.0, "bowl_depth": 180.0,   # inner (liner) surface
    "bowl_z0": 560.0,                                                  # inside floor of the bowl
    "liner_t": 8.0, "shell_t": 4.0,
    "rings": 4, "ring_first": 50.0, "ring_pitch": 38.0,                # ring height above the floor, pitch
    "ring_t": 6.0, "ring_depth": 12.0,                                 # axial thickness, radial depth of groove
    "fluid_hole_d": 1.0,
    # Fluidization jacket (item 4): GFRP, rotates with the bowl; rotary union at the spindle foot
    "jacket_gap": 12.0, "jacket_t": 4.0,
    "union_z": (114.0, 164.0), "union_d": 56.0,
    "hub_flange_d": 80.0, "hub_flange_t": 12.0, "hub_boss_d": 44.0, "hub_boss_h": 15.0, "hub_pcd": 60.0,
    # Spindle and bearings (item 5): 25 x 2 mm stainless tube (water passes up its bore)
    "spindle_d": 25.0, "spindle_wall": 2.0,
    "bearing_z": (235.0, 400.0), "bearing_d": 90.0, "bearing_h": 40.0, "bearing_flange": 95.0,
    "driven_pulley_d": 100.0, "pulley_z": 180.0,
    # Bowl brake (item 18): 160 mm bicycle disc rotor and mechanical caliper on the spindle
    "brake_rotor_d": 160.0, "brake_z": 360.0,
    # Splash tub (item 6) and lid guard (item 7)
    "tub_d": 430.0, "tub_z": (470.0, 790.0), "tub_t": 6.0, "lid_t": 10.0, "lid_hole_d": 60.0,
    "standpipe_d": 63.0, "standpipe_z": (445.0, 495.0), "tail_pipe_d": 75.0, "tail_pipe_z": 534.0,
    # Hopper and screen (item 2)
    "hopper_z": (960.0, 1180.0), "hopper_top_d": 340.0, "hopper_bot_d": 140.0, "screen_d": 360.0,
    "feed_pipe_d": 44.0, "feed_pipe_end": 815.0, "hopper_ring_z": 1000.0,
    # Drive (items 8 to 10)
    "pedal_x": -800.0, "bb_z": 438.0, "drive_z": 338.0, "jack_x": -250.0,
    "chainring_t": 48, "freewheel_t": 12, "bevel_ratio": 1.0, "drive_pulley_d": 300.0,
    "take_off_d": 140.0, "head_pulley_d": 125.0,
    "chain_y": 60.0, "belt_y": -330.0, "motor_chain_y": 373.5,
    "pillow_y": (-230.0, 250.0), "pillow_h": 33.0,
    "seat_z": 910.0, "crank_l": 170.0,
    # Motor option (item 12): reference hub motor on a cradle on the back lower rail
    "motor_x": -85.0, "motor_z": 376.0, "motor_y": (306.0, 366.0), "motor_r": 80.0,
    # Water header tank (item 13). Decided 2026-10-02 (GVS-DEC-001): the post rises to 1.7 m and is braced so a
    # full 60 L tank cannot tip it; the tank stands on the centre line (was 180 mm behind it) so that the taller
    # post does not make the machine easier to tip backward (GVS-CAL-001 section 11).
    "tank_x": -330.0, "tank_y": 0.0, "tank_d": 380.0, "tank_z": (1700.0, 2100.0),
    "brace_z": 1350.0,            # where the two braces meet the post (centre line)
    "brace_dx": 250.0,            # brace feet on the front and back top side rails, this far toward the table end
    "hose_run_z": 860.0,          # height of the hose's short run from the tank drop to the rotameter
    # Flush container (item 23): bought 10 L HDPE pail with a lid and a padlock hasp, loose on the ground in front
    # of the tub, where the operator rinses the rings into it (GVS-DEC-001, 2026-10-02, concentrate security)
    "flush_x": 100.0, "flush_y": -520.0, "flush_d": 250.0, "flush_h": 280.0,
    # Shaking table (items 14 to 16)
    "table_x0": 620.0, "table_l": 1000.0, "table_w": 450.0, "table_z": 820.0, "table_tilt": 3.0,
    "head_x": 560.0, "head_z": 710.0, "eccentric": 7.5,
    "flex_x": (680.0, 1540.0), "flex_y": 135.0, "flex_w": 80.0, "flex_t": 18.0,
    # Table bump stop (items 21 and 22, GVS-DDR-003 A2): rubber buffer on an M8 stud in a bracket bolted on the
    # frame's table-end top rail, striking an angle under the deck's back edge at the end of the forward stroke.
    # The model is drawn at the zero setting (buffer just touching at full forward travel); the working setting
    # turns the stud 3 mm toward the deck. The pitman pin works in a slot with 8 mm of lost motion.
    "stop_y": 205.0, "stop_z": 762.0, "buffer_d": 40.0, "buffer_l": 30.0, "pin_slot": 8.0,
}

STEEL = 7850.0          # kg/m3


@dataclass
class Comp:
    name: str
    shape: object
    color: str
    bom: int
    explode: tuple = (0, 0, 0)


# ------------------------------------------------------------------ primitives
def _box(x0, x1, y0, y1, z0, z1):
    from build123d import Box, Pos
    return Pos((x0 + x1) / 2, (y0 + y1) / 2, (z0 + z1) / 2) * Box(x1 - x0, y1 - y0, z1 - z0)


def _cyl(x, y, z0, z1, r):
    from build123d import Cylinder, Pos
    return Pos(x, y, (z0 + z1) / 2) * Cylinder(r, z1 - z0)


def _cyly(x, z, y0, y1, r):
    from build123d import Cylinder, Pos, Rot
    return Pos(x, (y0 + y1) / 2, z) * Rot(90, 0, 0) * Cylinder(r, y1 - y0)
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

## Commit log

2026-09-25 Initial scaffold: standard open hardware layout, CERN-OHL-S v2 + MIT licenses
    Claude-Session: https://claude.ai/code/session_01XuhhSU4W6fYhgCfURbrkut
    [bom.csv]
2026-09-25 Populate to TRL 2: problem, requirements, precis, concept media, BOM and README use cases
    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
    [bom.csv]
2026-09-26 Advance to TRL 3: DDR-001, CAL-001 sizing, parametric model with STEP/STL, GA drawing, priced BOM; TRL 4 on hold
    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
    [bom.csv, gravitysort-assembly.step, gravitysort-assembly.stl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]
2026-09-26 Accept all recommendations (DDR-002), switch footer to designmolecule.com, add README write-up with new inspiration point
    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
    [bom.csv, gravitysort-assembly.step, gravitysort-assembly.stl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]
2026-09-26 Strengthen sources, apply approved budgets, add CITATION.cff and CONTRIBUTORS.md with credits
    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
    [results.csv]
2026-09-27 Product appearance model and photoreal renders
    Adds cad/src/product_model.py (appearance model for renders only, all main
    dimensions from model.py) and Blender renders in media/render-*.png,
    captioned with the project, repository and viewing direction. README leads
    with the product render; trl stays 3.
    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
2026-10-01 Image quality pass: legible exploded views, flow diagrams and drawing sheets
    Kit 1.6.1 image layout: the parts list sits in its own column, number bubbles sit on visible parts and never overlap, small parts get a leader, pictures are cropped to the subject, flow labels keep numbers with their units, and sheet captions and the revision table no longer overprint. Concept images, blueprint and general arrangement sheet regenerated; repo-specific labels moved clear of other text and lines.
2026-10-01 Kit 1.7.0: constructable design, illustrated build plan and design decisions register
    The design is now constructable: every part can be made and fits its neighbours, with each change recorded in a Design for construction decision record (made under Amish's 2026-09-30 instruction; ope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
    FlexHand also credits Dr. Geeti Chadha as a contribut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
    [bom.csv, gravitysort-assembly.step, gravitysort-assembly.stl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]
2026-10-01 Record Amish's 2026-10-01 decisions
    GrowRider and GravitySort: Amish accepted the recommendations in the design decisions register ("i agree with your recommendations for both GrowRider and GravitySort"). Accepted items, including the 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
    [results.csv]
2026-10-01 PicoFlow full-bore valve, GravitySort bump stop, BioMedical cards
    PicoFlow: Amish accepted the full-bore inlet valve ("picoflow - i agree with the recommendation", 2026-10-01); the 125 mm full-bore gate valve replaces the 90 mm valve and its reducer and expander, output 85.6 W at 10 L/s (5.6 W over R3); model, calculations, build plan, pictures, register and PDFs updated. GravitySort: the accepted adjustable rubber bump stop is now in the model, drawings, build plan pictures and documents ("gravitysort - update the documentation, CAD work and picture renderings"). BreatheBox and DustBadge: social preview cards regenerated with the BioMedical area.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
    [bom.csv, gravitysort-assembly.step, gravitysort-assembly.stl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]
2026-10-02 Record Amish's approvals for PicoFlow, GravitySort and PalletPilot
    PicoFlow: clamp resistor changed to 6.8 ohm, 350 W; BOM insert size corrected to 34 mm ("I approve of your recommendations for PicoFlow and GravitySort"). GravitySort: slotted pitman pin and leaning legs that let the table reach the bump stop accepted. PalletPilot: about 40 degrees of steering each way accepted for the prototype, pitch wording corrected, and the TRL 4 aisle test made a go or no-go gate for the drive layout ("i accept your recommendations for PalletPilot"). PDFs regenerated.
2026-10-02 Record Amish's approval of the open-decision recommendations
    Amish approved the recommendation on every open decision in the design decisions register ("i approve your recommendations for all 555 open decisions.", 2026-10-02). Each decision is moved to Decisio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
2026-10-03 Carry approved follow-ups into the design and redo photoreal renders
    Amish approved the follow-up actions from the open-decision sign-off ("APPROVED CHANGES, COMPLETE THESE", 2026-10-02), the design-for-construction change tables in ten repos, the last wave's open dec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
    [bom.csv, gravitysort-assembly.step, gravitysort-assembly.stl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]
2026-10-03 Record Amish's 2026-10-03 decisions; FlatTrike fork and PotPress guard fixes
    Amish, 2026-10-03: "PalletPilot - i accept it"; "FlatTrike - i accept your design recommendation, proceed and execute the solution for fork direction or caster"; "PotPress - move forward with the four guard fixes. I accept the cost."; "GravitySort - i accept your recommendation"; "TIght Margins - i accept the margins"; "Cost over target - i accept all the cost variations and overruns". FlatTrike knuckle forks turned to trail (35 mm trail); PotPress finer mesh, small-hole plates, top beam and crank bracket covers, ISO 13857 desk check now met on paper. Registers, requirements, drawings, pictures, renders and PDFs upd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
2026-10-28 Kit 1.9.1 upgrade: pipeline documents and detailed CAD for every option
    Kit 1.9.1 installed (.kit, CLAUDE.md, .claude/commands). Kit 1.8 pipeline: STEM check with fixes under the 2026-10-23 standing instruction, concept options with the current design as option A, URS, PRS, generated RTM, REG, FEA, RSK with design FMEA, MKT, PLN and DDR; kit 1.9 D3 model of every option passing cad/fidelity.json; independent review recorded in the STEM check. Amish's 2026-10-25 decisions recorded where he approved a recommendation; all others proposed, awaiting Amish. Product renders and the options picture follow in a later commit where not yet included.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
2026-10-29 Add the concept options picture rendered from the D3 option models
    media/options.png from Blender Cycles panels of every option, rendered on Amish's Mac; the label reads CURRENT DESIGN unless project.yaml records Amish's choice. Clears the docs check, which needs th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

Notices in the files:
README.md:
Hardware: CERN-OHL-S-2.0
